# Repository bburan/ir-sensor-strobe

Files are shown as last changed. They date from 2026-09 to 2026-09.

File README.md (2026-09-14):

# Strobed IR Emitter / Sensor Board

A small four‑channel infrared emitter/detector board. Four IR LEDs (OP140) are
driven as a single strobed array; four phototransistors (OP550) act as
independent detectors, each presenting an analog output to a downstream
acquisition system.

The strobe carrier can come from either an **on‑board ~500 Hz oscillator** or an
**external control signal**, selected by a jumper at J1. The optoelectronics
mount remotely and connect through headers. The board is all through‑hole and is
intended to be hand‑soldered.

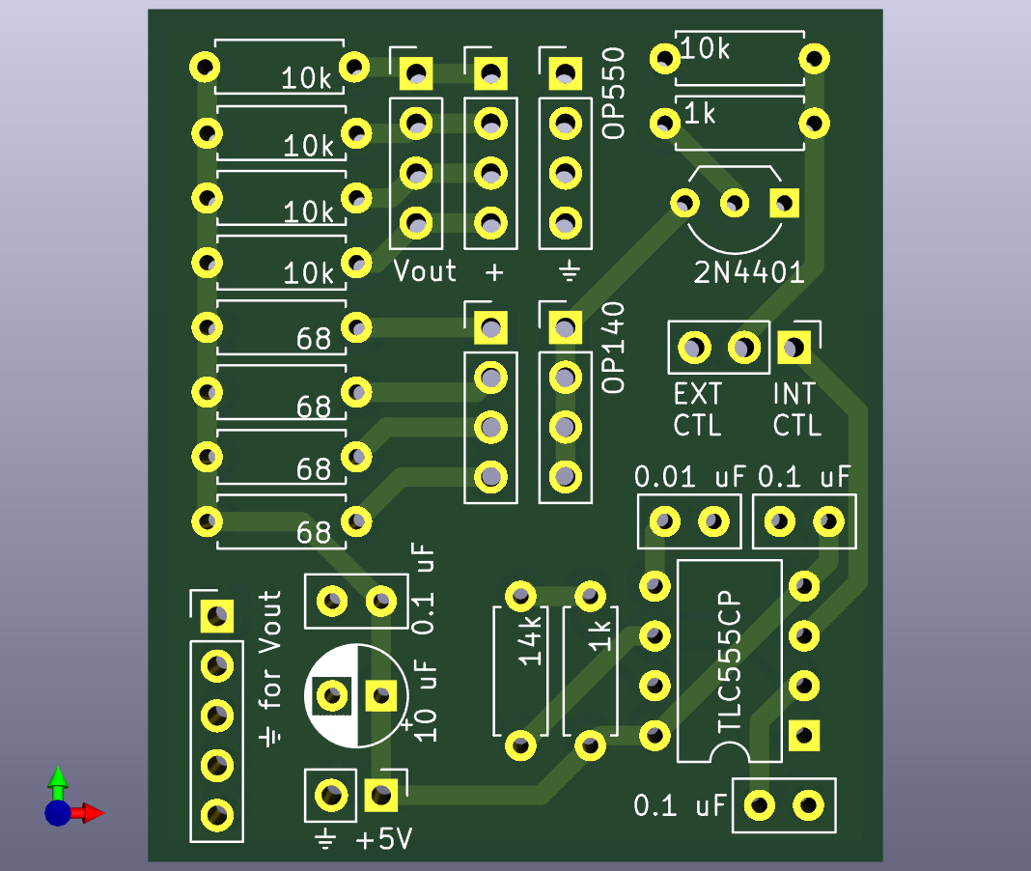
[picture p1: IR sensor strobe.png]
Board overview


---

## 1. Overview / Theory of Operation

The board contains three functional blocks that share a common +5 V / GND rail.

### 1.1 Strobed IR emitter (one switch, driving four LEDs)

```
 +5V ──┬─[68Ω R2]─▷|─ D1 ─┐
       ├─[68Ω R3]─▷|─ D2 ─┤
       ├─[68Ω R4]─▷|─ D3 ─┤   common cathode
       └─[68Ω R5]─▷|─ D4 ─┴────────────┐
                                        │ (collector)
   CTL ──┬─[1kΩ R1]── B  Q1 (2N4401)    ◄
         │                E ── GND
       [10kΩ R10]
         │
        GND
```

All four IR emitters (D1–D4, OP140) sit between the +5 V rail and a common node,
each with its own 68 Ω series resistor (R2–R5) setting the forward current to
roughly

```
I_LED ≈ (5 V − V_f − V_CE(sat)) / 68 Ω ≈ (5 − 1.5 − 0.2) / 68 ≈ 48 mA per LED
```

The common cathode node is pulled to ground by low‑side NPN switch **Q1**, driven
from the **CTL** node through the 1 kΩ base resistor **R1** (I_B ≈ 4.1 mA at 5 V).
When CTL is high, Q1 saturates and all four LEDs illuminate together; when CTL is
low the array is dark. Peak collector current in Q1 is the sum of the four
branches, **≈ 190 mA**.

R1 is deliberately left at 1 kΩ rather than a lower value. It has to be drivable
both by U1 and by an external source (see §1.2); dropping it to 470 Ω would gain
only ~5 % LED current while approaching the TLC555's ±10 mA output rating and
putting the external drive out of reach of a typical line‑level output.

The 10 kΩ resistor **R10** pulls CTL to ground so the array stays dark whenever
CTL is undriven or the J1 shunt is removed.

> **⚠ Q1 orientation differs between board revisions.** The current schematic
> uses an EBC pin mapping (pin 1 = emitter, pin 2 = base, pin 3 = collector),
> matching a standard TO‑92 2N4401 installed **per the silkscreen**.
>
> Boards fabricated from the *earlier* netlist have pads 1 and 3 transposed, and
> need Q1 inserted **rotated 180°** (flat face opposite the silkscreen). Built
> the other way round, Q1 runs reverse‑active (β_R ≈ 5–20 instead of ≈ 150) and
> the emitters run several times dim with nothing obviously wrong. See §6 for the
> one‑meter check that tells the two cases apart.

### 1.2 Strobe source — on‑board oscillator or external (J1)

```
                 +5V
                  │
                [1k R11]
                  │
    ┌─────────────┴── DIS (7)
    │                            ┌──────┐          J1
  [14k R12]      U1  TLC555 ─────┤ Q (3)├──── 1  ○ INT CTL
    │                            └──────┘         │
    ├─────────────┬── THR (6)                   2  ○ ── CTL ── R1 → Q1 base
    │             └── TR  (2)                      │
 [0.1µ C3]                                       3  ○ EXT CTL ── external drive
    │
   GND
```

**U1** is a TLC555 wired as a standard astable:

```
f = 1.44 / ((R11 + 2·R12) · C3) = 1.44 / ((1k + 28k) · 0.1 µF) ≈ 497 Hz
D = (R11 + R12) / (R11 + 2·R12) = 15k / 29k ≈ 51.7 %
```

C4 (0.01 µF) decouples the control‑voltage pin; C5 (0.1 µF) is local supply
bypass. RESET (pin 4) is tied to +5 V.

**J1 selects the strobe source** — the silkscreen marks the two ends **INT CTL**
and **EXT CTL**:

| Shunt | Source | Use |
|---|---|-----|
| **1–2** | On‑board oscillator (U1) | Board self‑strobes at ~497 Hz. No host output needed. |
| **2–3** | External drive | Host supplies the carrier on pin 3. |

With no shunt fitted, R10 holds CTL low and the array stays dark.

A CMOS TLC555 is specified rather than a bipolar NE555 deliberately: its output
swings close to the rails (a bipolar 555 drops ~1.7 V, starving Q1's base) and it
does not inject the large supply transients an NE555 does on each edge, which
matters on a board carrying 10 kΩ‑impedance analog sensor lines.

**Why ~50 % duty.** For a square carrier of fixed peak current, the amplitude
recovered at the fundamental is (2·I_pk/π)·sin(πD), maximised at D = 0.5. The
maximum is flat, so the astable's 51.7 % costs about 0.15 % — the diode trick
often used to force exactly 50 % is unnecessary here.

### 1.3 Photodetectors (four independent channels)

```
 +5V ──[10kΩ]──┬──────► Vout (to J2 / J6)
               │ C
              (Q_photo, OP550)
               │ E
              GND (J5)
```

Each phototransistor (Q2–Q5, OP550) is wired common‑emitter: collector pulled to
+5 V through a 10 kΩ load resistor (R6–R9), emitter to ground. The output is
taken at the collector:

* **Dark / no IR:** phototransistor off → output pulled high (≈ +5 V).
* **Illuminated:** phototransistor conducts → output pulled toward ground.

The response is therefore **inverting**. The four channels are electrically
independent; only the emitter array is strobed, in common.

The detectors are *not* modulated — only the emitters are. Recovering the signal
at the carrier frequency (e.g. quadrature demodulation at ~497 Hz) rejects
ambient light, mains‑derived flicker, and the DC offset of each phototransistor,
which is what makes the board usable through an AC‑coupled input.

### 1.4 Notes and caveats

* **Supply bypassing is on‑board.** C1 (10 µF) + C2 (0.1 µF) sit across the
  +5 V/GND entry at J4 to absorb the ~190 mA switching transient of the emitter
  array. Additional bulk upstream never hurts on a long supply lead.
* **CTL has an on‑board pulldown.** R10 (10 kΩ) holds CTL low when undriven or
  unjumpered, so the array defaults to dark. Any 3.3–5 V logic high will switch
  Q1.
* **The emitters cannot be gated individually.** One switch drives all four. The
  detectors are read individually.
* **No reverse‑polarity or over‑current protection.** Observe supply polarity at
  J4 — C1 is polarized and a reversed supply will stress it along with Q1 and the
  phototransistors.

---

## 2. Bill of Materials (what to order)

Quantities are per board. All parts are through‑hole. 27 placements, 75 joints.

| Ref(s) | Qty | Value / Part | Package / Footprint | Notes |
|---|-----|---|---|---|
| R1, R11 | 2 | 1 kΩ | Axial ¼ W, 7.62 mm pitch (DIN0207) | Q1 base resistor; 555 charge resistor |
| R2, R3, R4, R5 | 4 | 68 Ω | Axial ¼ W, 7.62 mm pitch | LED ballast, ~48 mA each (82 mW worst case) |
| R6, R7, R8, R9 | 4 | 10 kΩ | Axial ¼ W, 7.62 mm pitch | Phototransistor collector load |
| R10 | 1 | 10 kΩ | Axial ¼ W, 7.62 mm pitch | CTL pulldown |
| R12 | 1 | 14 kΩ | Axial ¼ W, 7.62 mm pitch | 555 timing (E96 value) |
| C1 | 1 | 10 µF | Radial electrolytic, 2.5 mm pitch (polarized)| Bulk bypass at J4; observe polarity |
| C2, C3, C5 | 3 | 0.1 µF | Ceramic disc, 2.5 mm pitch | C2 supply HF bypass, C3 555 timing, C5 U1 local bypass |
| C4 | 1 | 0.01 µF | Ceramic disc, 2.5 mm pitch | 555 control‑voltage decoupling |
| U1 | 1 | TLC555CP | DIP‑8, 7.62 mm row spacing | **CMOS** 555 — do not substitute NE555 (see §1.2) |
| Q1 | 1 | 2N4401 | TO‑92 (inline) | EBC pinout. **See orientation warning in §1.1** |
| J1 | 1 | 3‑pin header | 2.54 mm PinHeader 1×03 | Strobe source select (INT CTL / EXT CTL) |
| J2 | 1 | 4‑pin header | 2.54 mm PinHeader 1×04 | Detector outputs to acquisition |
| J3 | 1 | 5‑pin header | 2.54 mm PinHeader 1×05 | Ground bus for the Vout harness |
| J4 | 1 | 2‑pin header | 2.54 mm PinHeader 1×02 | Power in: pin 1 = +5 V, pin 2 = GND |
| J5 | 1 | 4‑pin header | 2.54 mm PinHeader 1×04 | OP550 return (emitters, all GND) |
| J6 | 1 | 4‑pin header | 2.54 mm PinHeader 1×04 | OP550 out (collectors) |
| J7 | 1 | 4‑pin header | 2.54 mm PinHeader 1×04 | OP140 in (common cathode return) |
| J8 | 1 | 4‑pin header | 2.54 mm PinHeader 1×04 | OP140 out (anodes) |

**Off‑board optoelectronics** (not on the PCB, wired via the harness — see §3.2):

| Ref(s) | Qty | Part | Notes |
|---|-----|---|---|
| D1, D2, D3, D4  | 4 | OP140 IR emitter | Anode to J8, cathode to J7 |
| Q2, Q3, Q4, Q5  | 4 | OP550 phototransistor | Collector to J6, emitter to J5 |

**Emitter/detector wavelength.** Confirm the detector's spectral response
overlaps the emitter's output for your specific parts before ordering in
quantity, and consult current datasheets for lead configuration.

**Sourcing note.** Through‑hole ICs are being discontinued industry‑wide. If
TLC555CP (DIP‑8) becomes hard to source, the SOIC‑8 TLC555CD is cheaper and
better stocked, but requires a footprint change.

---

## 3. Assembly

All through‑hole, hand‑solder friendly. Nothing requires reflow. Budget roughly
20–30 minutes per board.

### 3.1 Soldering order

Populate lowest‑profile parts first so the board sits flat while you work:

1. **Resistors R1–R12** (axial). Bend leads to the 7.62 mm pitch, seat flat,
   solder, trim. Non‑polar. Double‑check value groups:
   * R1, R11 = 1 kΩ
   * R2–R5 = 68 Ω (LED ballast)
   * R6–R9 = 10 kΩ (detector load)
   * R10 = 10 kΩ (CTL pulldown)
   * R12 = 14 kΩ (555 timing) — easy to confuse with the 10 kΩ group
2. **Ceramic caps C2, C3, C4, C5** (non‑polar) and **transistor Q1** (TO‑92).
   **Check §1.1 for Q1's orientation before soldering — it depends on which board
   revision you have.** Seat Q1 with a few mm of lead so the case is not stressed.
3. **U1** (DIP‑8). Match pin 1 to the notch/dot on the silkscreen. A socket is
   worth fitting if you expect to experiment with the timing components.
4. **Headers J1–J8.** Solder one pin, reflow while pressing the header flush and
   square, then solder the rest. Pin 1 of each connector is the
   **square/rectangular pad**.
5. **Electrolytic cap C1** (10 µF, **polarized**). Match the `+` lead to the `+`
   pad; the silkscreen band indicates the negative side.

Clean flux as appropriate and inspect for bridges, especially at the connector
rows.

### 3.2 Remote optoelectronics harness

The OP140 emitters and OP550 detectors are **not** mounted on the PCB. They are
wired on flying leads so they can be positioned on a fixture — aimed across a
nose‑poke or lick spout, for example. Four headers carry them:

| Header | Silk | Carries | Pin mapping |
|---|---|---|---|
| **J8** | OP140 | LED **anodes** (one per channel, each via its own ballast) | pin 1 → D4, pin 2 → D3, pin 3 → D2, **pin 4 → D1** |
| **J7** | OP140 | LED **cathodes** — all four pins common, returning to Q1 | any pin; one per LED keeps the harness symmetric |
| **J6** | OP550 | Detector **collectors** (the outputs) | pin 1 → Q2, pin 2 → Q3, pin 3 → Q4, pin 4 → Q5 |
| **J5** | OP550 | Detector **emitters** — all four pins are GND | one per detector, giving each channel its own return |

> **⚠ J8's pin order is reversed** relative to the D1–D4 reference designators
> (pin 1 is D4, pin 4 is D1). J6 runs in order (pin 1 = Q2 … pin 4 = Q5). Check
> this when building the harness; getting it backwards silently swaps which
> physical emitter pairs with which detector channel.

Polarity out at the remote device still matters: the OP140 anode goes to J8 and
its cathode to J7; the OP550 collector goes to J6 and its emitter to J5. A
reversed LED will not emit; a reversed phototransistor will not conduct properly.

Giving each detector its own return conductor to J5 rather than daisy‑chaining
them keeps inter‑channel ground coupling down on long harnesses.

---

## 4. PCB Fabrication (what to order)

Generate Gerbers/drill from `IR sensor strobe.kicad_pcb` (KiCad 8:
*File → Fabrication Outputs → Gerbers* and *Drill Files*), or order directly from
the KiCad project at any standard fab.

| Parameter | Value |
|---|---|
| Layers | 2 (F.Cu / B.Cu) |
| Board size | ≈ 37.5 mm × 43.5 mm |
| Thickness | 1.6 mm |
| Material | FR‑4 |
| Finish | HASL or ENIG (either is fine — all THT)|
| Min feature | Default KiCad clearances; no fine‑pitch parts, so any vendor's economy process is adequate |
| Silkscreen | Both sides used (title/attribution on back) |

There are no controlled‑impedance, high‑voltage, or thermal requirements.

The back silkscreen reads *"Strobed IR emitter/sensor w/ internal generator"*,
which distinguishes this revision from the earlier board — worth checking before
assembly, since Q1's orientation differs between the two (§1.1).

**If ordering assembled:** the board is 100 % through‑hole, which is the
worst‑priced category at every CM because it is hand‑soldered. At low quantity
hand assembly is usually cheaper than the setup fees. If assembly cost matters at
volume, converting the passives to 0805 and U1 to SOIC‑8 moves the bulk of the
work onto automated SMT and leaves only the nine connectors to solder by hand.

---

## 5. Connector Pinout & Usage

| Connector | Pins | Signal | Direction | Description |
|---|---|---|---|---|
| **J4** (Power) | 1 | +5 V | in | Board supply. |
| | 2 | GND  | in | Supply return. |
| **J1** (CTL select) | 1 | INT CTL | — | On‑board oscillator output (U1 pin 3). |
| | 2 | CTL | — | Q1 base drive. Shunt 1–2 for internal, 2–3 for external. |
| | 3 | EXT CTL | in | External strobe input. Logic high → all IR LEDs on. |
| **J2** (Vout)  | 1–4 | Vout[1..4] | out | The four detector outputs, same nets as J6. High ≈ dark, low ≈ illuminated. |
| **J3** (GND) | 1–5 | GND | — | Ground bus; all five pins common. Return/reference for the Vout harness. |
| **J5** (OP550 return) | 1–4 | GND | — | Detector emitter returns. |
| **J6** (OP550 out) | 1–4 | Vout[1..4] | — | Detector collectors — the remote sensor cable. |
| **J7** (OP140 in) | 1–4 | LED common cathode | — | All four pins common, returning to Q1's collector. |
| **J8** (OP140 out) | 1–4 | LED anodes | — | One per channel, **reverse order** — see §3.2. |

J2 and J6 are the same four nets: J6 faces the remote sensor harness, J2 faces
the acquisition system. That is deliberate fan‑out, not a duplicate.

### Typical connection

1. Supply **+5 V / GND** to **J4** (on‑board bypass C1/C2 handles local
   decoupling — see §1.4).
2. Fit the **J1** shunt: **1–2** to let the board strobe itself at ~497 Hz, or
   **2–3** and drive **EXT CTL** from a host timer/GPIO.
3. Wire the remote optoelectronics to **J5–J8** per §3.2.
4. Read the four **J2 (Vout)** channels on the host, referenced to a **J3**
   ground, and demodulate at the carrier frequency.

---

## 6. Bring‑up / Test

1. **Unpowered:** verify J4 polarity. A resistance check from +5 V to GND will
   briefly show C1/C2 charging before settling high — it should **not** read a
   hard short. Confirm C1's polarity.
2. **Power, no J1 shunt:** apply +5 V. R10 holds CTL low, so the array is dark.
   Each Vout on J2 should read ≈ +5 V (detectors dark, pulled up through 10 kΩ).
   Quiescent current is small.
3. **Oscillator:** fit the J1 shunt on **1–2** and scope U1 pin 3. Expect a
   roughly square wave near **497 Hz at ~52 % duty**, swinging close to the
   rails. If it sits stuck at either rail, check RESET (pin 4) is at +5 V and
   that R12 is the 14 kΩ part, not a stray 10 kΩ.
4. **Emitter current — the Q1 orientation check.** With the strobe running,
   measure the DC voltage across any one 68 Ω ballast (R2–R5):
   * **≈ 1.6 V** (≈ 24 mA average at 50 % duty) → Q1 is correctly oriented.
   * **Well under 0.5 V** → Q1 is reverse‑active. Re‑read §1.1 and flip it.

   Confirm IR emission with a phone camera (a faint pale/purple glow on many
   sensors) or an IR‑sensitive card.
5. **Detector response:** with the emitters running, illuminate a detector
   (reflect off a nearby surface, or point an IR source at it). Its Vout should
   show the carrier, and the amplitude should collapse when the beam is blocked.
   Repeat per channel.
6. **End to end:** demodulate each channel at the carrier frequency and confirm
   that breaking the beam produces a large, unambiguous amplitude drop.

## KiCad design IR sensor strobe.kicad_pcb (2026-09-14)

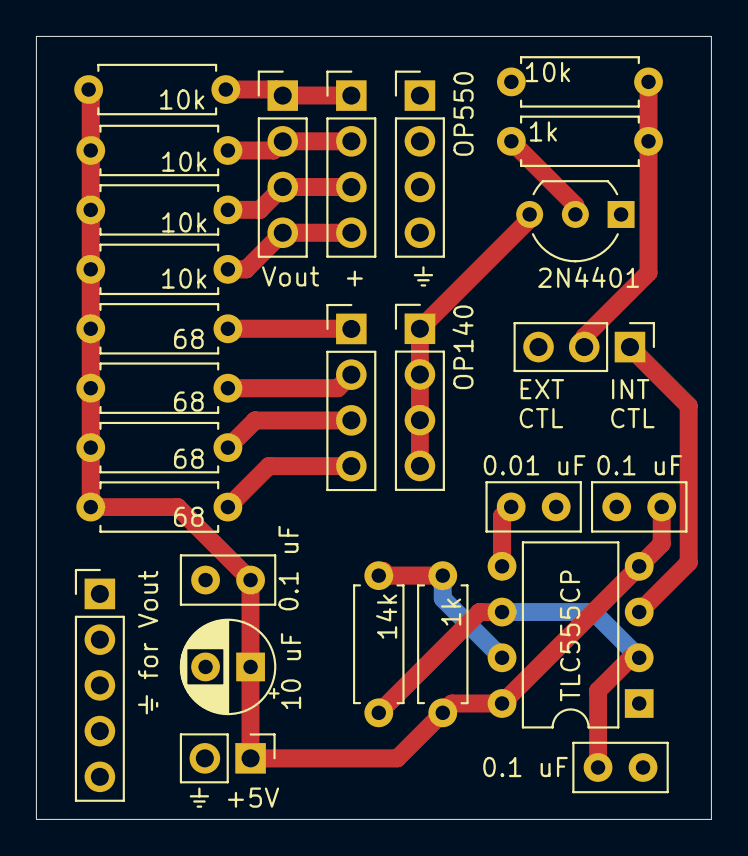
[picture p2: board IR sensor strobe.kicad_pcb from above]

Board: 2 copper layers, 37.5 x 43.5 mm, 27 parts (0 on the bottom side), 17 nets.

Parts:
C1: 10 uF; CP_Radial_D5.0mm_P2.50mm
C2, C3, C5: 0.1 uF; C_Disc_D5.0mm_W2.5mm_P2.50mm
C4: 0.01 uF; C_Disc_D5.0mm_W2.5mm_P2.50mm
J1: CTL select; PinHeader_1x03_P2.54mm_Vertical
J2: Sensors; PinHeader_1x04_P2.54mm_Vertical
J3: Conn_01x05; PinHeader_1x05_P2.54mm_Vertical
J4: Conn_01x02; PinHeader_1x02_P2.54mm_Vertical
J5: OP550 return; PinHeader_1x04_P2.54mm_Vertical
J6: OP550 out; PinHeader_1x04_P2.54mm_Vertical
J7: OP140 in; PinHeader_1x04_P2.54mm_Vertical
J8: OP140 out; PinHeader_1x04_P2.54mm_Vertical
Q1: 2N4401; TO-92_Inline_Wide
R1, R11: 1k; R_Axial_DIN0207_L6.3mm_D2.5mm_P7.62mm_Horizontal
R2, R3, R4, R5: 68; R_Axial_DIN0207_L6.3mm_D2.5mm_P7.62mm_Horizontal
R6, R7, R8, R9, R10: 10k; R_Axial_DIN0207_L6.3mm_D2.5mm_P7.62mm_Horizontal
R12: 14k; R_Axial_DIN0207_L6.3mm_D2.5mm_P7.62mm_Horizontal
U1: TLC555CP; DIP-8_W7.62mm

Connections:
+5V: C1.1, C2.1, C5.1, J4.1, R2.1, R3.1, R4.1, R5.1, R6.1, R7.1, R8.1, R9.1, R11.1, U1.4 (R), U1.8 (VCC)
/OSC: J1.1, U1.3 (Q)
GND: C1.2, C2.2, C3.2, C4.2, C5.2, J3.1, J3.2, J3.3, J3.4, J3.5, J4.2, J5.1, J5.2, J5.3, J5.4, Q1.1 (E), R10.2, U1.1 (GND)
unnamed: J1.2, R1.2, R10.1
unnamed: J2.1, J6.1, R6.2
unnamed: J2.2, J6.2, R7.2
unnamed: J2.3, J6.3, R8.2
unnamed: J2.4, J6.4, R9.2
unnamed: J7.1, J7.2, J7.3, J7.4, Q1.3 (C)
unnamed: J8.1, R5.2
unnamed: J8.2, R4.2
unnamed: J8.3, R3.2
unnamed: J8.4, R2.2
unnamed: Q1.2 (B), R1.1
unnamed: C4.1, U1.5 (CV)
unnamed: R11.2, R12.1, U1.7 (DIS)
unnamed: C3.1, R12.2, U1.2 (TR), U1.6 (THR)

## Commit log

2026-09-09 Add assembly/ordering README and initialize repo
    Document the strobed IR emitter/sensor board: theory of operation,
    bill of materials, soldering/assembly steps, PCB fab spec, connector
    pinout, and bring-up procedure. Add .gitignore for KiCad cache,
    backups, and editor lock files.
    [IR sensor strobe.kicad_pcb, IR sensor strobe.kicad_sch]
2026-09-14 Add supply decoupling and CTL pull-down; move emitters/detectors off-board
    Schematic and README work predating the oscillator change:
    - Add C1 (10 uF) and C2 (0.1 uF) across the +5 V / GND entry at J4 to
    absorb the ~200 mA switching transient of the emitter array.
    - Add R10 (10k) pull-down on CTL so the emitter array stays dark when
    CTL is undriven.
    - D1-D4 (OP140) and Q2-Q5 (OP550) carry no footprints; they are remote
    parts wired through J5-J8. PCB nets renamed accordingly.
    - README updated to match.
    INCONSISTENT SNAPSHOT -- this revision is not a coherent design state.
    The .kicad_pcb captured here had already been re-imported from the
    *later* schematic, so it contains U1, R11, R12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
    [IR sensor strobe.kicad_pcb, IR sensor strobe.kicad_sch]
2026-09-14 Add on-board 500 Hz strobe oscillator; fix Q1 pinout; shrink resistors
    Lets the board self-strobe so the DAQ/sound-card analog output is no
    longer needed to generate the carrier.
    Oscillator:
    - U1 TLC555 astable (R11 1k, R12 14k, C3 0.1 uF) -> 497 Hz at ~52% duty.
    f = 1.44 / ((R11 + 2*R12) * C3). C4 (0.01 uF) on CV, C5 (0.1 uF) local
    supply decoupling. RESET tied to +5 V.
    - J1 becomes a 1x3 jumper: pin 1 OSC, pin 2 CTL, pin 3 EXT.
    Jumper 1-2 selects the on-board oscillator, 2-3 external drive.
    R10 still holds CTL low when the shunt is removed.
    - R1 left at 1k so an external source (sound-card output) can still
    drive CTL without exceeding the TLC555's +/-10 mA output rating.
    Q1 pin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
    [IR sensor strobe.kicad_sch]
2026-09-14 PCB: normalize footprint text rotations after re-import
    KiCad rewrites rotation 360 as 0 on save. No positional or netlist
    change.
    Note: the substantive PCB re-import (U1, R11, R12, C3-C5, and the
    DIN0207 resistor footprints) was already present on disk and landed in
    eb6598a, whose message describes only the pre-oscillator work.
    [IR sensor strobe.kicad_pcb]
2026-09-14 README: document on-board oscillator, jumper, and remote harness
    Brings the README in line with the current board:
    - New section on the TLC555 strobe source and the J1 INT/EXT jumper,
    including why a CMOS 555 is specified and why ~52% duty is fine.
    - Q1 documented as 2N4401 with a prominent warning that its orientation
    differs between board revisions, plus a bring-up measurement that
    distinguishes the two cases.
    - BOM rebuilt: adds U1, R11, R12, C3-C5, J5-J8; J1 is now 1x03; resistor
    pitch corrected to 7.62 mm; ceramic pitch corrected to 2.5 mm.
    - Replaces the stale "2-pad + / ground-symbol footprint" text, which
    described emitter/detector footprints that no longer exist, with the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
2026-09-14 Regenerate board photo for the current layout
    Exported from the KiCad 3D viewer, replacing an image that was two
    revisions stale (it still showed the 2-pad emitter/detector footprints,
    12.70 mm resistors, and no C1/C2 or oscillator).
    Now shows U1 (TLC555CP), Q1 as 2N4401, the J1 EXT CTL / INT CTL jumper,
    R11/R12, C3-C5, and the J5-J8 harness headers. Same 1068x902 framing as
    before.
